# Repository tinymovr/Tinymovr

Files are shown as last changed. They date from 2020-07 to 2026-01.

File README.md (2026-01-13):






[Tinymovr is an affordable motor controller](https://tinymovr.com) with integrated encoder and CAN bus for precise control of 3-phase brushless motors (PMSMs). 

This repository holds the open source firmware, client library, hardware designs and documentation source.

> **Note**
>
> This is the latest stable version of the Tinymovr Firmware and Studio app. For the legacy 0.x.x version, check out the [legacy branch](https://github.com/tinymovr/Tinymovr/tree/attic/legacy).

## Getting Started

Please visit the [Quick Start Guide](https://tinymovr.readthedocs.io/en/latest/quickstart.html)

## Getting Help

[Full documentation is available at Readthedocs](https://tinymovr.readthedocs.io).

Please visit the [Discussions Page](https://github.com/tinymovr/Tinymovr/discussions) and the [Discord Server](https://discord.gg/vNvmpfthug) to ask any questions. If you are unable to find an answer to your question, you are welcome to [start a new discussion](https://github.com/tinymovr/Tinymovr/discussions/new/choose) or ask away at [our Discord server](https://discord.gg/vNvmpfthug).

If you would like to propose a feature or think you have found a bug, [open a new issue](https://github.com/tinymovr/Tinymovr/issues/new).

### Repository Structure

> **Note**: The `main` branch reflects the latest release. Development happens on [develop](https://github.com/tinymovr/Tinymovr/tree/develop).

The repository is organized as follows:

[firmware](./firmware/): Firmware for the PAC5527 MCU in Tinymovr

[studio](./studio/): Tinymovr Studio client software and library

[hardware](./hardware): Designs and drawings for related hardware

[docs](./docs): User documentation source (built with Sphinx)

See also: Developer documentation in root (ARCHITECTURE.md, CONTRIBUTING.md, etc.)

### Developer Documentation

For contributors and AI agents working with the codebase:

- **[ARCHITECTURE.md](ARCHITECTURE.md)** - System design and module organization
- **[CONTRIBUTING.md](CONTRIBUTING.md)** - Setup, workflow, and PR process
- **[SAFETY.md](SAFETY.md)** - Safety-critical constraints (read before modifying firmware)
- **[CLAUDE.md](CLAUDE.md)** - Navigation guide for AI agents

Additional technical documentation:
- [AVLOS_GUIDE.md](AVLOS_GUIDE.md) - Protocol modification workflow
- [CONVENTIONS.md](CONVENTIONS.md) - Code style and patterns
- [TESTING.md](TESTING.md) - Testing practices
- [STRUCTURE.md](STRUCTURE.md) - Directory organization
- [PAC5527_NOTES.md](PAC5527_NOTES.md) - MCU architecture

## Versioning

We use [SemVer](http://semver.org/) for versioning. For the versions available, see the [tags on this repository](https://github.com/tinymovr/tinymovr/tags). 

## Contributing

Pull requests are welcome. For major changes, please open an issue first to discuss what you would like to change.

**New contributors**: See [CONTRIBUTING.md](CONTRIBUTING.md) for setup instructions and workflow.

**AI agents**: See [CLAUDE.md](CLAUDE.md) for navigation and guidelines.

## License

[GPLv3](https://choosealicense.com/licenses/gpl-3.0/)

### External Links

[Tinymovr Website and Store](https://tinymovr.com)

[Blog](https://tinymovr.com/blogs/news)

[Discord server](https://discord.gg/vNvmpfthug)

[Project page on Hackaday](https://hackaday.io/project/168650-tinymovr-motor-controller)

[BLDC-Design-Help Repository](https://github.com/ThotAlion/BLDC-design-help), with lots of useful information and Tinymovr benchmarks

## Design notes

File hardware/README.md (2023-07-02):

### Tinymovr Hardware

This folder contains 3D models and drawings of the Tinymovr motor controller and associated hardware.

- [STEP files for Tinymovr R5.x and related accessories](./R5/)
- [STEP files for Tinymovr M5.x and related accessories](./M5/)
- [Tinymovr R3 STEP files](./R3/)
- [STL and STEP files for the Tinymovr Servo Kit, R2 and R5](./ServoKit/)
- [STEP files for the ACT8.3 Actuator](./Actuator/)
- [Miscellaneous STL/step files](./misc/), like a [jig for centering encoder magnets](./misc/magnet_jig.stl)

[CANine schematic files and models are now in a separate repository](https://github.com/tinymovr/CANine/tree/main/Hardware)

Unless otherwise specified, all designs are released under the MIT License.

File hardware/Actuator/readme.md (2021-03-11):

# ACT8.3 Actuator

ACT8.3 is a belt driven actuator with a 8.3:1 reduction, for the Tinymovr motor controller. In this video, I am testing the actuator up to 1.7Nm torque@15A.

This actuator uses the Tinymovr motor controller:

https://tinymovr.com

The actuator can be easily 3D printed on an FDM printer, with no supports.

The following Bill of Materials is recommended:

- 1x Tinymovr Motor Controller
- 1x Tarot 4108 Motor
- 1x 6705ZZ 25x32x4mm bearing
- 1x 6702ZZ 15x21x4mm bearing
- 2x 693ZZ 3x8x4mm bearings
- 2x GT2 158mm length 6mm width belts
- 1x GT2 Timing Pulley 12 teeth 4mm bore 6mm belt width
- 10x M2 threaded inserts
- 6x M2 bolts, 20mm length

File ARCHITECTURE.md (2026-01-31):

# Tinymovr System Architecture

**Document Type**: Architectural overview
**Target Audience**: AI agents, developers new to the codebase
**Focus**: System structure and design patterns, not implementation details

## Quick Reference

### Entry Points
- **Firmware Entry**: [firmware/src/main.c](firmware/src/main.c)
- **Control Loop**: [firmware/src/controller/controller.c](firmware/src/controller/controller.c)
- **API Specification**: [studio/Python/tinymovr/specs/](studio/Python/tinymovr/specs/)
- **Python Client**: [studio/Python/tinymovr/](studio/Python/tinymovr/)

### Related Documentation
- [SAFETY.md](SAFETY.md) - Safety-critical constraints for motor control
- [PAC5527_NOTES.md](PAC5527_NOTES.md) - MCU hardware architecture
- [AVLOS_GUIDE.md](AVLOS_GUIDE.md) - Communication protocol system
- [CLAUDE.md](CLAUDE.md) - Practical development guide

## System Components

Tinymovr consists of **two separate projects**:

### 1. Firmware (Embedded C)
- **Location**: [firmware/](firmware/)
- **Target**: Qorvo PAC5527 MCU (ARM Cortex-M4F)
- **Purpose**: Real-time motor control (Field-Oriented Control)
- **Architecture**: Bare-metal (no RTOS)
- **Build**: GNU Make + arm-none-eabi-gcc

### 2. Studio (Python)
- **Location**: [studio/Python/](studio/Python/)
- **Target**: Host computer (Linux, macOS, Windows)
- **Purpose**: User interface and motor configuration
- **Architecture**: Schema-driven client (Avlos framework)
- **Build**: Python package (pip install)

### Communication
- **Physical**: CAN bus (CAN 2.0B extended ID), UART
- **Protocol**: Avlos (schema-driven, auto-generated from YAML)
- **Direction**: Bidirectional (host ↔ firmware)

## Firmware Architecture

### Design Principles

1. **Real-Time**: Fixed 20 kHz control loop with <50 μs deadline
2. **Safety-First**: Automatic error detection and safe state transitions
3. **Modular**: 17 independent modules with clear responsibilities
4. **Cooperative Scheduling**: Single thread, interrupt-driven synchronization
5. **Resource-Constrained**: 32 KB RAM, 128 KB Flash

### Module Organization

**Location**: [firmware/src/](firmware/src/)

| Module | Purpose | Key Responsibilities |
|---|---|---|
| **main** | Entry point | Initialization sequence, startup |
| **system** | Platform | Clock config, reset, voltage monitoring |
| **controller** | Control | FOC loops (position → velocity → current) |
| **motor** | Motor mgmt | Calibration (R, L, pole pairs) |
| **sensor** | Encoder I/O | Multiple encoder types (MA7xx, AS5047, AMT22, Hall) |
| **observer** | State est. | Position/velocity estimation from encoder |
| **adc** | Sensing | Current measurement, ADC trigger |
| **gatedriver** | Actuation | PWM generation, Space Vector Modulation |
| **can** | Comm | CAN bus interface, Avlos endpoint dispatch |
| **uart** | Comm | UART interface (alternative to CAN) |
| **ssp** | I/O | SPI for external encoders |
| **nvm** | Storage | Configuration persistence to flash |
| **scheduler** | Timing | Interrupt sync, CPU load monitoring |
| **watchdog** | Safety | Communication timeout detection |
| **timer** | Hardware | PWM timer configuration |
| **utils** | Math | Fast trig, SVM algorithm |
| **rtt** | Debug | SEGGER RTT output (optional) |

**Dependencies**: See [ARCHITECTURE.md Module Map](#module-dependencies) for detailed dependency graph.

### Control Flow

#### Initialization
```
main() entry
  ↓
System initialization (clocks, peripherals)
  ↓
Load configuration from flash (or defaults)
  ↓
Initialize modules (ADC, CAN, timers, watchdog)
  ↓
Enable interrupts
  ↓
Enter control loop (never returns)
```

#### Control Loop Structure
```
Infinite loop:
  ├─ Error checking (overcurrent, undervoltage, etc.)
  ├─ State machine dispatch:
  │   ├─ IDLE: Motors disabled, safe state
  │   ├─ CALIBRATE: Multi-stage calibration sequence
  │   └─ CL_CONTROL: Closed-loop control active
  └─ Wait for ADC interrupt (20 kHz synchronization point)
```

#### Closed-Loop Control (when in CL_CONTROL state)
```
Every 50 μs (20 kHz):
  ├─ Read sensors (encoder, current)
  ├─ Update observers (position, velocity estimation)
  ├─ Position loop (if enabled): pos_error → vel_setpoint
  ├─ Velocity loop (if enabled): vel_error → current_setpoint
  ├─ Current loop (always): current_error → voltage_setpoint
  ├─ Space Vector Modulation: voltage → PWM duties
  └─ Update PWM outputs
```

### State Machine

**States**:
- **IDLE**: Safe state, motors off
- **CALIBRATE**: Executing calibration sequence
- **CL_CONTROL**: Closed-loop control active

**Transitions**:
- User command → State change
- Any error → Automatic transition to IDLE
- Watchdog timeout → Automatic transition to IDLE
- Calibration complete → Automatic transition to IDLE

**Safety**: Errors always force IDLE state. This cannot be disabled.

### Interrupt Architecture

**Priority** (highest to lowest):
1. **ADC IRQ** - Control loop synchronization (20 kHz)
2. **CAN RX** - Incoming messages
3. **UART RX** - Incoming messages (if using UART)
4. **SysTick** - System timing (1 kHz)
5. **Watchdog** - Safety timeout

**Design**: Short ISRs (<10 μs), set flags for main loop processing.

### Calibration System

**Multi-Stage Sequence** (all executed at 20 kHz):
1. **ADC Offset**: Zero current sensors (~1 second)
2. **Resistance (R)**: DC voltage/current measurement (~2 seconds)
3. **Inductance (L)**: AC impedance measurement (~1 second)
4. **Pole Pairs**: Rotation counting (variable duration)
5. **Encoder**: Eccentricity compensation (variable duration)

**Safety Features**:
- Voltage limits per board revision
- Range checking on measured values
- Warm-up and debouncing (recent addition)
- Automatic failure handling

### Memory Organization

**Flash** (128 KB):
- Bootloader: 4 KB @ 0x00000000
- Application: 124 KB @ 0x00001000

**RAM** (32 KB):
- Application: 31.75 KB
- Bootloader shared: 256 bytes

**Optimization**: Critical functions marked for RAM execution (zero wait states).

### Board Revision Support

Multiple hardware revisions supported via compile-time configuration:
- **R3.x**: Original design
- **R5.x**: Updated layout, improved EMI
- **M5.x**: Gimbal motor variant (lower current)

**Differences**: CAN pin assignments, current limits, calibration parameters.

## Studio Architecture (Python)

### Design Principles

1. **Schema-Driven**: API auto-generated from YAML specifications
2. **Device-Agnostic**: Supports multiple firmware versions simultaneously
3. **Unit-Aware**: Physical units (Pint library integration)
4. **Hardware-in-the-Loop**: Comprehensive test infrastructure
5. **Multi-Device**: Multiple Tinymovr devices on same bus

### Key Components

**Location**: [studio/Python/tinymovr/](studio/Python/tinymovr/)

| Component | Purpose |
|---|---|
| **specs/** | YAML API specifications (one per firmware version) |
| **config/** | Spec loading, device discovery, hash matching |
| **bus_router** | Message distribution to multiple devices |
| **bus_manager** | CAN bus connection with auto-reconnect |
| **channel** | Per-device communication channel |
| **device_discovery** | Automatic device detection via heartbeat |
| **codec** | Binary serialization/deserialization |
| **cli** | IPython-based command-line interface |
| **gui/** | Qt-based graphical interface |
| **tests/** | Hardware-in-the-loop test suite |

### Communication Stack

```
Application
  ↓
Device Object (dynamically generated from YAML spec)
  ↓
CANChannel (per device, identified by node_id)
  ↓
BusRouter (singleton, message distribution)
  ↓
BusManager (wraps python-can, auto-reconnect)
  ↓
python-can library
  ↓
CAN hardware adapter (CANine, slcan, socketcan, etc.)
```

### Schema-Driven API (Avlos)

**Workflow**:
```
YAML Spec
  ↓
avlos.generate (code generation tool)
  ├─→ Firmware C code (can_endpoints.c/h)
  ├─→ Firmware enums (tm_enums.h)
  └─→ Documentation (RST files)

YAML Spec (at runtime)
  ↓
avlos.deserialize
  ↓
Python Object Tree (dynamic attribute access)
```

**Benefits**:
- Single source of truth
- Firmware and client always synchronized
- Protocol versioning via hash
- Self-documenting API

### Device Discovery

**Process**:
1. Listen for CAN heartbeat messages
2. Extract protocol hash from heartbeat
3. Match hash to YAML spec
4. Deserialize spec into Python object
5. Create device instance

**Result**: Automatic instantiation of correct client version for each device.

### Testing Infrastructure

**Test Types**:
- **Simulation**: No hardware required, logic validation
- **HITL**: Hardware-in-the-loop, requires physical Tinymovr
- **Sensor-Specific**: Tests for particular encoder types
- **End-of-Line**: Comprehensive production tests

**Test Markers** (pytest):
- `@pytest.mark.hitl_default`
- `@pytest.mark.sensor_amt22`
- `@pytest.mark.sensor_as5047`
- `@pytest.mark.sensor_hall`
- `@pytest.mark.eol`
- `@pytest.mark.dfu`

## Communication Protocol (Avlos)

### Design

- **Schema-Driven**: Defined in YAML, not hand-coded
- **Hierarchical**: Tree structure of attributes
- **Typed**: Strong type system (float, uint32, bool, enums, etc.)
- **Versioned**: Protocol hash ensures compatibility
- **Bidirectional**: Read/write/call operations

### CAN Bus Encoding

**Arbitration ID** (29-bit extended):
- Node ID field (device address)
- Protocol hash field (version identifier)
- Endpoint ID field (parameter/function identifier)

**Payload**:
- Binary serialization (little-endian)
- Up to 8 bytes per frame
- Type-specific encoding (float, int, string, etc.)

### Version Management

**Multi-Version Support**:
- Multiple YAML specs for different firmware versions
- Runtime hash matching
- Graceful degradation if hash mismatch
- Hash aliases for backward compatibility

## Hardware Architecture

### Supported Boards

| Revision | Family | Application | Current Range |
|---|---|---|---|
| R3.x | R3 | High-current | 5-30 A |
| R5.x | R5 | High-current (improved) | 5-30 A |
| M5.x | M5 | Gimbal motors | 1-10 A |

**Compile-Time Selection**: `make release REV=R52`

### Encoder Support

**Types**:
1. MA7xx (MPS magnetic) - Onboard
2. AS5047 (AMS magnetic) - External SPI
3. AMT22 (CUI absolute) - External SPI
4. Hall effect - 3× digital inputs

**Normalization**: All encoders normalized to 13-bit resolution (8192 ticks/rev).

**Dual Sensor**: Supports simultaneous commutation and position sensors.

## Key Design Decisions

### Firmware

1. **No RTOS**: Bare-metal for predictability and low overhead
2. **Fixed 20 kHz PWM**: Simplifies timing analysis, above audible range
3. **RAM Execution**: Critical functions run from RAM for deterministic timing
4. **Cooperative Scheduling**: Single control thread, no preemption
5. **Automatic Safety**: Errors force IDLE state, cannot be disabled

### Studio

1. **Schema-Driven**: Avlos framework eliminates manual wrapper coding
2. **Dynamic Objects**: Python objects created at runtime from YAML
3. **Unit System**: Pint integration for physical units
4. **Multi-Device**: BusRouter enables multiple devices on one bus
5. **Version Agnostic**: Supports multiple firmware versions simultaneously

### Protocol

1. **CAN Bus**: Industry-standard, reliable, multi-drop
2. **Extended ID**: 29-bit allows encoding of version and endpoint
3. **Binary Encoding**: Efficient, minimal bandwidth
4. **Hash Versioning**: Detects incompatibilities automatically

## Module Dependencies

### Firmware Core Dependencies

```
main
 ├─→ system (clocks, reset)
 ├─→ nvm (config loading)
 ├─→ adc (current sensing)
 ├─→ can (communication)
 ├─→ uart (alternative comm)
 ├─→ timer (PWM setup)
 ├─→ watchdog (safety)
 └─→ controller (control loop)
      ├─→ motor (calibration, parameters)
      ├─→ observer (state estimation)
      │    └─→ sensor (encoder reading)
      │         └─→ ssp (SPI for external encoders)
      ├─→ gatedriver (PWM output)
      │    └─→ timer (hardware config)
      └─→ scheduler (timing sync)
```

### Studio Core Dependencies

```
Application
 └─→ Device (from config.create_device)
      ├─→ CANChannel (from channel.py)
      │    ├─→ BusRouter (singleton from bus_router.py)
      │    │    └─→ BusManager (from bus_manager.py)
      │    │         └─→ python-can
      │    └─→ MultibyteCodec (from codec.py)
      └─→ Avlos-generated attributes (from specs/*.yaml)
           └─→ Pint units (if unit specified in YAML)
```

## Critical File Reference

### Firmware
- [firmware/src/main.c](firmware/src/main.c) - Entry point
- [firmware/src/controller/controller.c](firmware/src/controller/controller.c) - Control loop
- [firmware/src/motor/motor.c](firmware/src/motor/motor.c) - Calibration
- [firmware/src/config.h](firmware/src/config.h) - System constants
- [firmware/src/common.h](firmware/src/common.h) - Board revisions, includes
- [firmware/Makefile](firmware/Makefile) - Build system

### Studio
- [studio/Python/tinymovr/specs/](studio/Python/tinymovr/specs/) - API definitions (YAML)
- [studio/Python/tinymovr/config/config.py](studio/Python/tinymovr/config/config.py) - Spec loading
- [studio/Python/tinymovr/bus_router.py](studio/Python/tinymovr/bus_router.py) - Message routing
- [studio/Python/tinymovr/channel.py](studio/Python/tinymovr/channel.py) - Device communication
- [studio/Python/tests/tm_test_case.py](studio/Python/tests/tm_test_case.py) - Test base class

### Protocol
- [avlos_config.yaml](avlos_config.yaml) - Code generation config
- [firmware/src/can/can_endpoints.h](firmware/src/can/can_endpoints.h) - Generated endpoints (C)
- [firmware/src/tm_enums.h](firmware/src/tm_enums.h) - Generated enums (C)

## Build System

### Firmware Build

**Toolchain**: GNU ARM Embedded (arm-none-eabi-gcc)
**Build Tool**: GNU Make
**Targets**: `debug`, `release`, `clean`
**Board Selection**: `REV=R53` (or R52, M51, etc.)

**Linker Script**: [firmware/pac55xx.ld](firmware/pac55xx.ld) - Memory layout

### Studio Build

**Python Version**: 3.9+
**Package Manager**: pip
**Install**: `pip install -e .` (editable mode)
**Optional GUI**: `pip install -e .[gui]`

### Code Generation

**Tool**: Avlos (Python package)
**Command**: `avlos from file <spec_file>.yaml`
**Input**: YAML specs in [studio/Python/tinymovr/specs/](studio/Python/tinymovr/specs/)
**Output**: C code, enums, documentation

## Development Environment

### Required Tools

**Firmware**:
- arm-none-eabi-gcc
- GNU Make
- PAC55xx SDK (download from Qorvo)
- Optional: J-Link debugger

**Studio**:
- Python 3.9+
- CAN interface hardware
- pytest (for testing)

**Documentation**:
- Sphinx
- Furo theme

### Debug Interfaces

**Firmware**:
- SWD/JTAG (pins: SWDIO, SWCLK)
- SEGGER RTT (zero-overhead debug output)

**Studio**:
- python-can debug logging
- pytest verbose output

## Cross-References

For detailed information, see:
- **Safety Constraints**: [SAFETY.md](SAFETY.md)
- **MCU Hardware**: [PAC5527_NOTES.md](PAC5527_NOTES.md)
- **Protocol System**: [AVLOS_GUIDE.md](AVLOS_GUIDE.md)
- **Development Guide**: [CLAUDE.md](CLAUDE.md)
- **Contributing**: [CONTRIBUTING.md](CONTRIBUTING.md)
- **User Documentation**: [docs/](docs/)

---

**Document Focus**: Architectural patterns and structure, not implementation details.
**For Implementation**: See source code and related documentation above.

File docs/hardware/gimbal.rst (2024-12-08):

.. _gimbal-motors:

*************
Gimbal Motors
*************

.. |cli| raw:: html

   <span style="padding:3px 10px;margin: 10px auto; background:#85dff1; border-radius: 12px; font-family: sans-serif; font-size: 14px;">CLI</span>

.. |gui| raw:: html

   <span style="padding:3px 10px;margin: 10px auto; background:#85f1df; border-radius: 12px; font-family: sans-serif; font-size: 14px;">GUI</span>

.. _gimbal-introduction:

Introduction
------------

Tinymovr can drive gimbal-style brushless motors in open loop current control, by disabling current sensing. 

.. warning::
   * This mode is not recommended for Tinymovr M5, which is a specialized gimbal driver and can do closed loop current control with gimbal motors.

What is a gimbal motor anyway?

A gimbal motor is a 3-phase brushless motor whose stator is wound with many turns, and as such exhibits much larger resistance and inductance compared to the high-current brushless motors used to provide lift to drones, rc planes etc. Gimbal motors are used in... well... camera gimbals mainly. Similar motors can be found in light robotic joints. Such motors offer smooth motion and require small currents to produce torque compared to the 'high current' brushless motors. This in turn can help minimize the size of the motor driver and associated wires etc. Note that we refer to reduction of current through the stator windings and not the power converted to heat as a result of Joule heating of stator windings, which is still the same for the same amount of torque.

To achieve closed-loop current control, motor controllers such as Tinymovr use current measurement resistors in each phase (usually in series with the low-side mosfet) to estimate the current in the motor windings. These resistors have low resistance (in the range of a few milliOhms at most), to limit power dissipation in the resistor and allow operation in wide current ranges (up to several tens of Amps, even hundreds). The drawback is that current measurements exhibit noise of 100s of mA, and as such do not offer accurate measurements of small currents.

The gimbal mode of Tinymovr disables closed-loop current control. The commanded currents are converted to voltages using basic resistance and inductance formulas. 

.. _enabling-gimbal-mode:

Enabling Gimbal Mode
--------------------

.. warning::
   * DO NOT perform calibration on a gimbal motor without setting gimbal mode first! There is a risk of damaging the motor and board.
   
   * Using arbitrary resistance and inductance settings can damage your motor and board.

To enable gimbal mode, set the motor configuration as follows:

|gui|

|cli|

.. code-block:: python

    >>>tm1.motor.type = 1 # gimbal type
    >>>tm1.motor.R = {motor_resistance}
    >>>tm1.motor.L = {motor_inductance}
    >>>tm1.motor.I_cal = {calibration_current}

Example

.. code-block:: python

    >>>tm1.motor.type = 1
    >>>tm1.motor.R = 5
    >>>tm1.motor.L = 2e-3
    >>>tm1.motor.I_cal = 0.5

     >>>tm1.set_motor_RL(5, 0.002)

This specifies a motor with 5 Ohms resistance, 2 Millihenries inductance and 0.5Amps calibration current.
Alternatuvely, using the units interface:

.. code-block:: python

    >>>tm1.motor.type = 1 # gimbal type
    >>>tm1.motor.R = 5 * Ohm
    >>>tm1.motor.L = 2e-3 * Henry
    >>>tm1.motor.I_cal = 0.5 * Amps

Control that the settings are correct:

|cli|

.. code-block:: python
    
    >>>tm1.motor

Ensure the values above are correct. You can now calibrate the motor:

|gui| Set Gimbal Motor Parameters

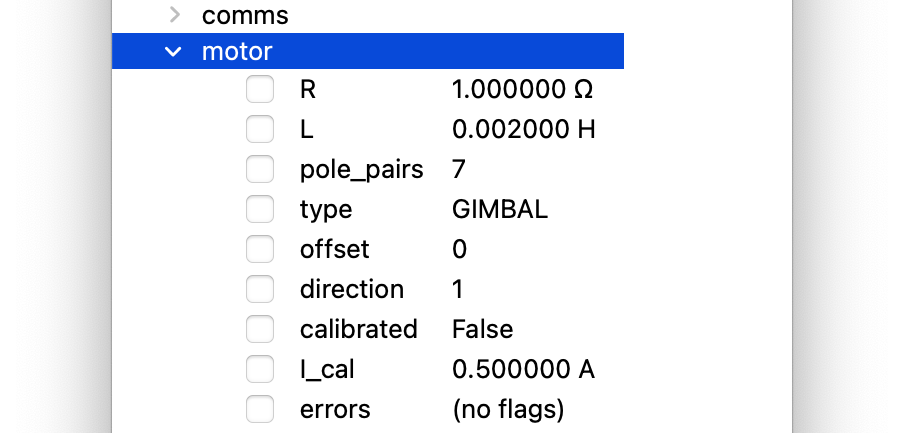
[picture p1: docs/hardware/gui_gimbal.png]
Set Gimbal Motor Parameters


|cli|

.. code-block:: python
    
    >>>tm1.controller.calibrate()

Because the motor is set as gimbal, calibration will bypass resistance and inductance measurement, and will only calculate pole pairs, offset and direction. After calibration `tm1.motor.calibrated` should have a value of True:

|gui| Calibrate Motor

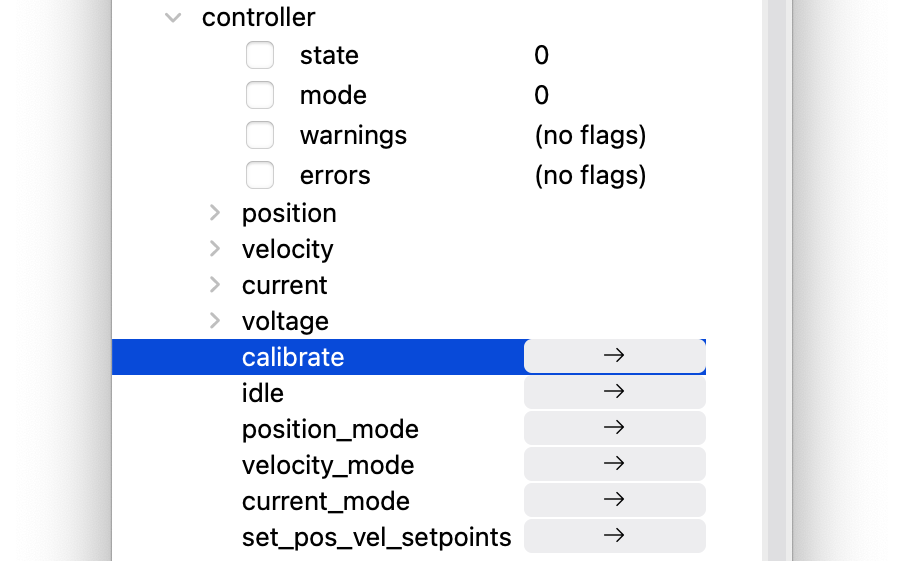
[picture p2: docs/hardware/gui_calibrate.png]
Calibrate Motor


|cli|

.. code-block:: python
    
    >>>tm1.motor.calibrated
    True

Controlling the Motor
---------------------

Gimbal mode has identical functionality as the default high-current mode. Position, velocity and current control modes are supported. Depending on your motor charaacteristics, you may have to tune the control gains to achieve optimal performance. In addition, due to the fact that current control is open loop, high angular velocities may not be available.

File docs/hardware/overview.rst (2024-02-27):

.. _hardware-overview:

*****************
Hardware Overview
*****************

R5.x
****

Tinymovr R5.x is the latest Tinymovr revision. It features increased connectivity in a reduced footprint.

Board Dimensions (R5.0, R5.1)
#############################

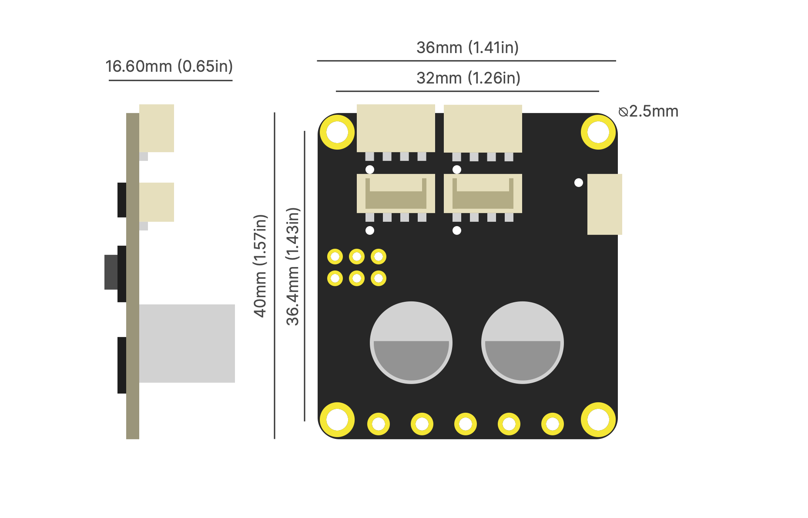
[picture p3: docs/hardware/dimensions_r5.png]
Tinymovr R5 dimensions


Connectivity (R5.0, R5.1)
#########################

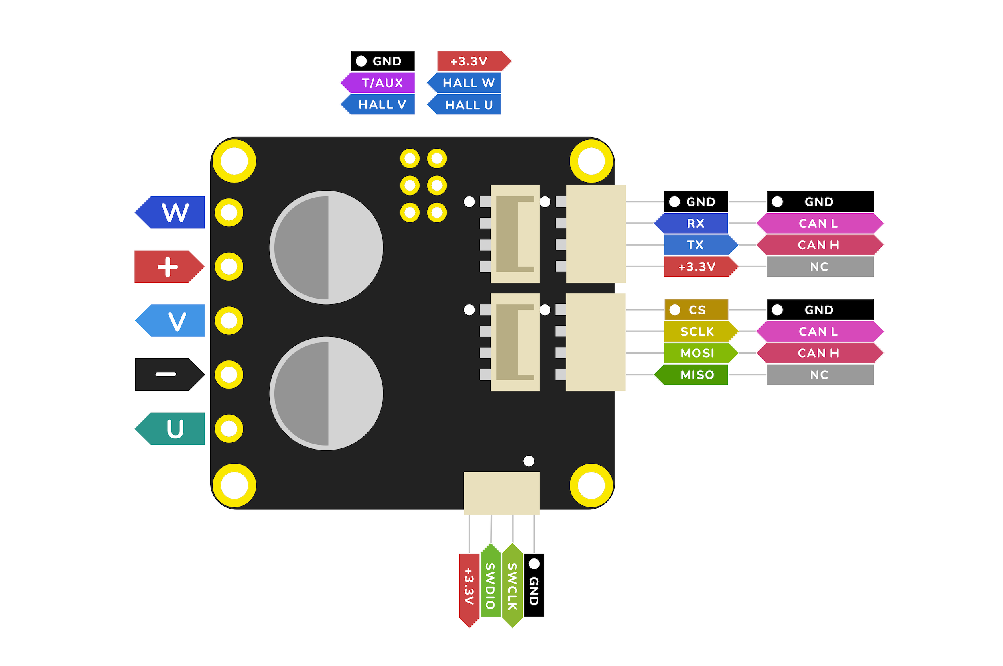
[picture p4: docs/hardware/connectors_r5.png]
Tinymovr R5 connectors and pinouts


.. warning::
   The UART pins in Tinymovr R5.1 have the silkscreen reversed. If you are planning to use UART with R5.1, consult :ref:`r51-erratum-1`. This only affects R5.1 boards.

Board Dimensions (R5.2)
#######################

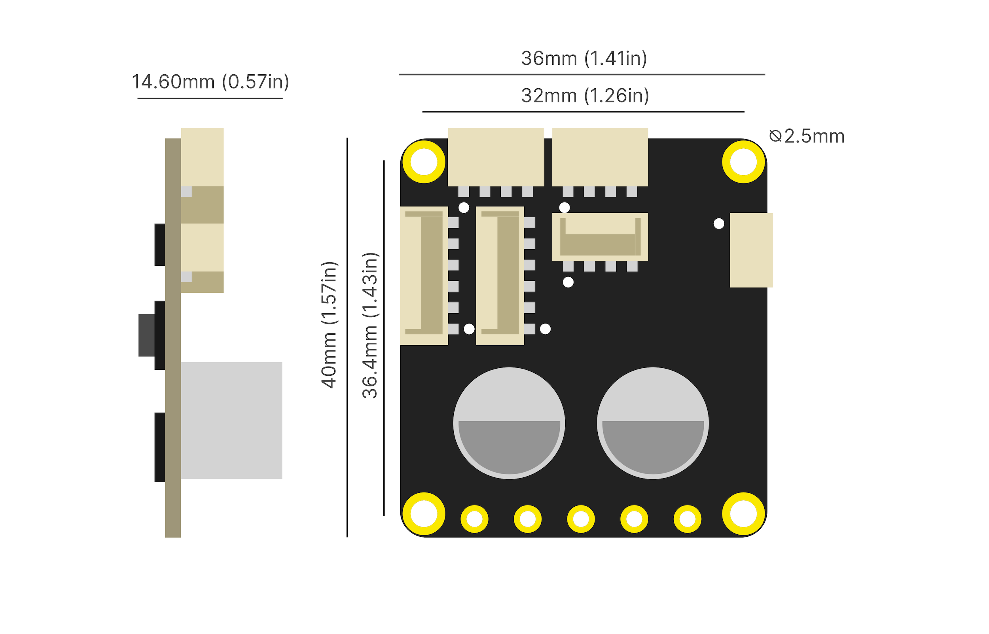
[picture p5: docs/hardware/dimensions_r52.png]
Tinymovr R5.2 dimensions


Connectivity (R5.2)
###################

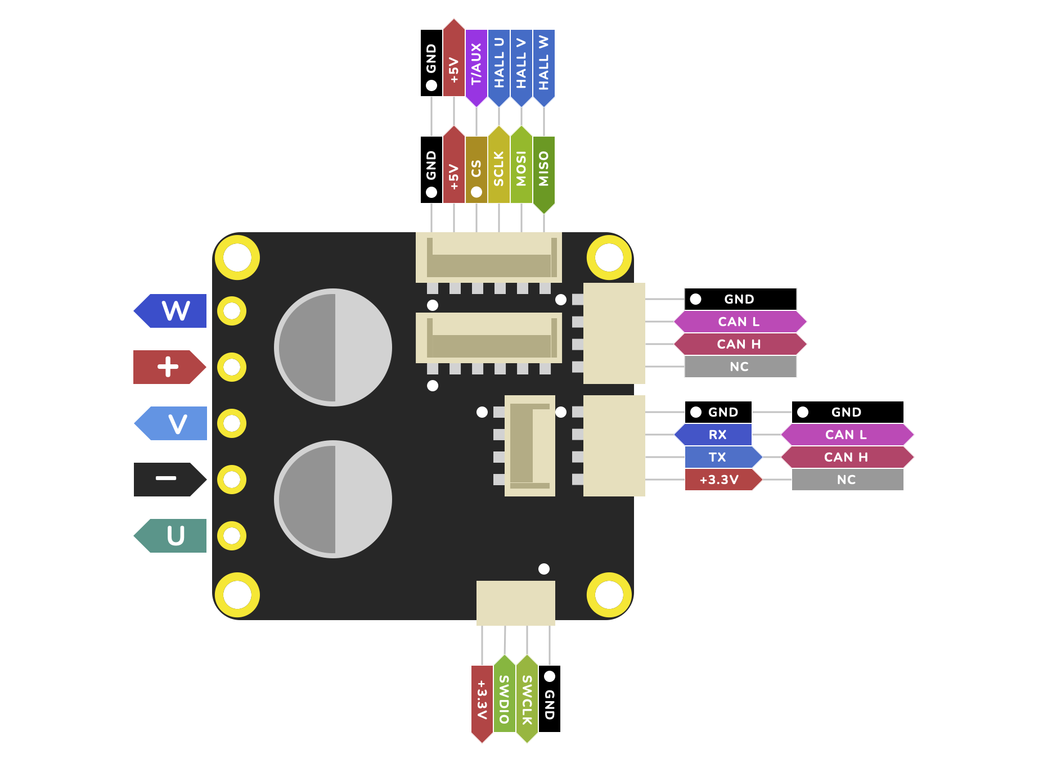
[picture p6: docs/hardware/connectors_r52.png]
Tinymovr R5.2 connectors and pinouts


M5.x
****

Tinymovr M5.x is is our specialized driver for gimbal motors and light robotic joints. It features a very compact footprint and 5A max drive.

Board Dimensions (M5.1, M5.2)
#############################

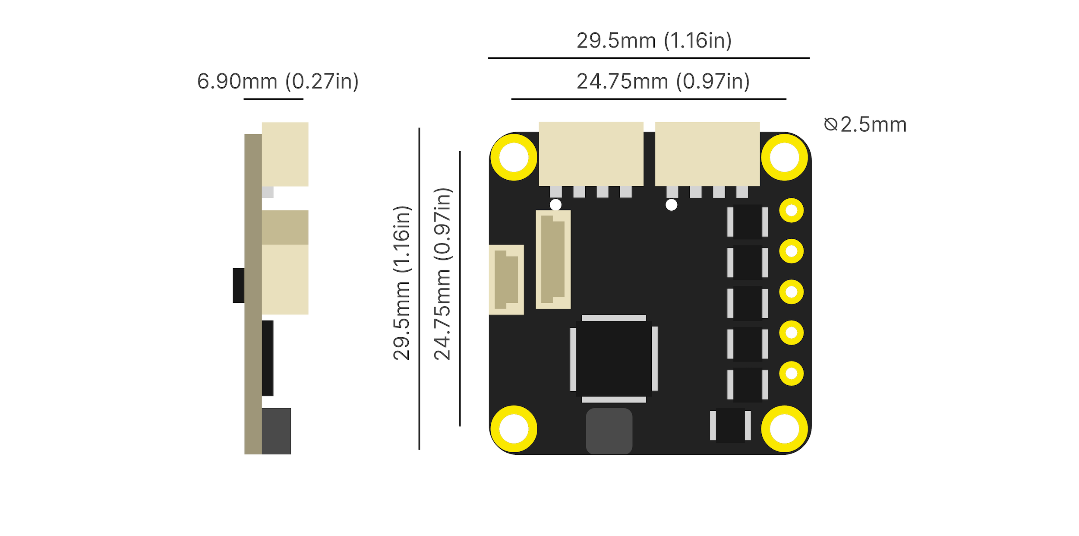
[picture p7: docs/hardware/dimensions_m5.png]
Tinymovr M5 dimensions


Connectivity (M5.1)
#########################

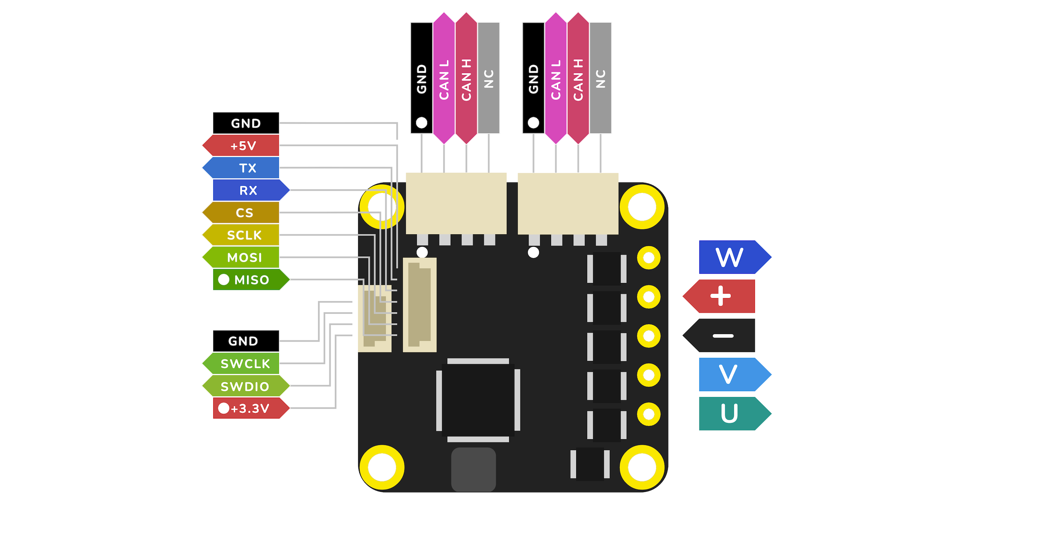
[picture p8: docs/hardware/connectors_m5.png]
Tinymovr M5.1 connectors and pinouts


Connectivity (M5.2)
#########################

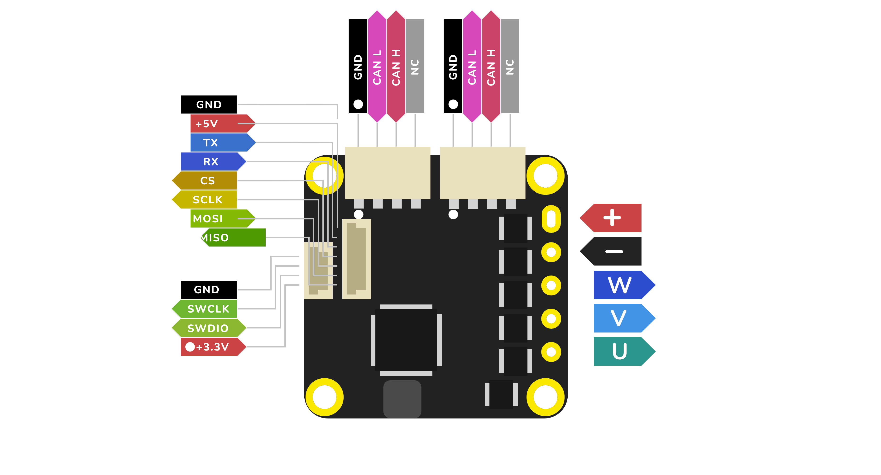
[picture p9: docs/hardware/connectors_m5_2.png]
Tinymovr M5.2 connectors and pinouts


R3.x
****************

R3.x is the previous Tinymovr revision, with CAN and UART connectivity.

Board Dimensions (R3.x)
#######################

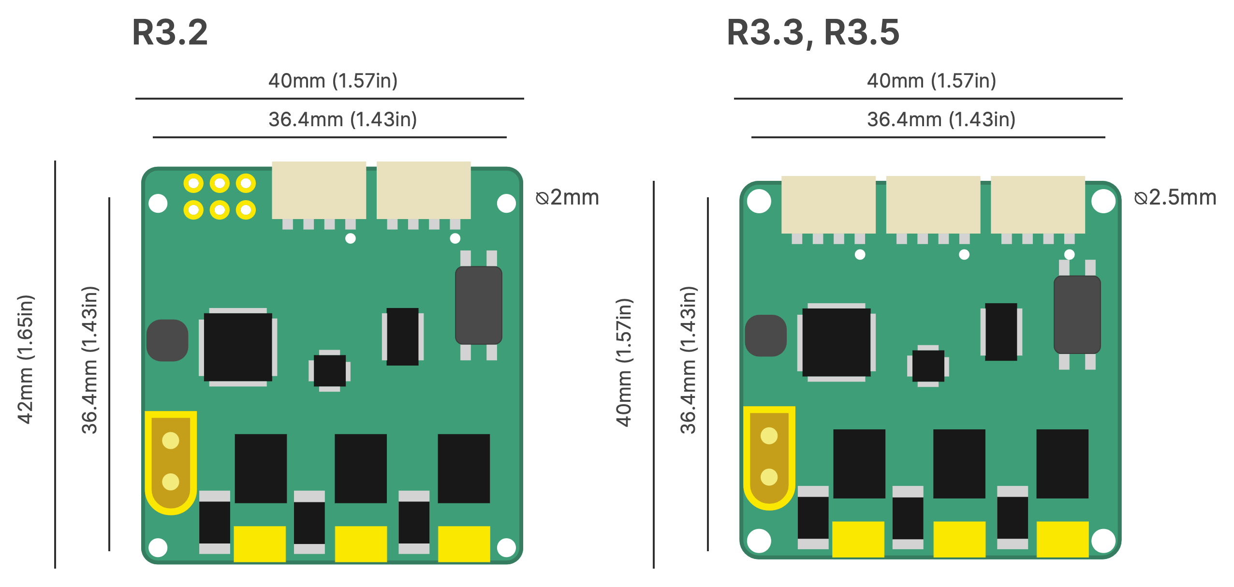
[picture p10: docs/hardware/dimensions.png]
Tinymovr R3.x dimensions


Connectivity (R3.x)
###################

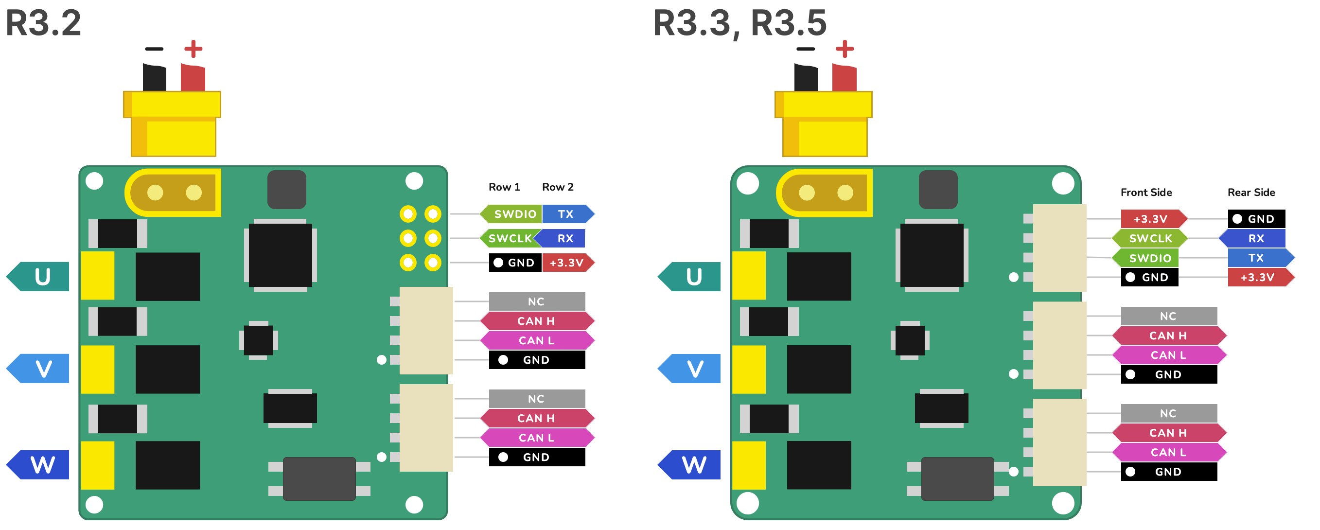
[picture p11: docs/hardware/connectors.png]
Tinymovr R3.x connectors and pinouts


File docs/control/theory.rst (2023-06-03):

.. _Control theory:

******************
Control Principles
******************

This document provides a high-level introduction to the essential control principles in Tinymovr. Additional documentation regarding specific high-level control concepts is available in the :ref:`features` section.

Permanent Magnet Synchronous Motors (PMSMs)
###########################################

PMSMs is a category which includes the majority of hobby-grade brushless motors. PMSMs produce torque through the interaction of the magnetic field of the rotor permanent magnets with the magnetic field generated by the stator coils. The stator magnetic field "rotates" at a rate that is an integer multiple of the rotor rate of rotation, this is why this type of motor is termed "synchronous". 

This is also why, the motor controlled needs to be able to estimate the angular position of the rotor, in order to derive the stator magnetic field that produces torque. Many controllers estimate the rotor using magnetic encoder readings, which is then converted to electrical angle in software. This is termed *sensored estimation*, and this is the method employed in Tinymovr. In contrast, ESCs such as those used in drones use voltage feedback from one of the motor phases to estimate rotor position. This is termed *sensorless estimation*.

Field Oriented Control (FOC)
############################

Field Oriented Control (FOC) is a control scheme employed in brushless motor applications, offering superior performance compared to other algorithms. Although FOC requires more computational power due to its complexity, advancements in technology have made it increasingly accessible. Modern 32-bit microcontrollers can now execute FOC algorithms at high rates, contributing to its widespread adoption. By directly controlling the current in the motor phases, FOC enables precise torque management, resulting in enhanced performance and efficiency for various applications.

The FOC algorithm comprises three main elements:

1. Precise 3-phase current estimation
2. Transformation of 3-phase measurements to rotating frame.
3. Regulation of the rotational frame variables.

Measuring Phase Currents
************************

In order for FOC to work, the currents in the three phases (U, V, W) of the motor must be precisely estimated. This is done with the help of shunt resistors. Shunt resistors are high-power elements with low, precisely known resistance values, that are placed in series to the low-side mosfet sources, and enable current measurement by measuring the voltage differential across their terminals. Hardware and software filtering techniques improve current measurement accuracy.

As the motor phases are connected, current measurement in each of the three phases is redundant, and measurement in two phases would theoretically suffice. Nonetheless, having all three measurements allows for better accuracy through averaging of measurement errors. This is why Tinymovr uses three phase current measurement.

Reference Frames
****************

Next, the 3-phase measurements are transformed to the rotating frame of the rotor which is termed dq. The relevant transformation is known as the dq0 transform. The resulting quantities are the direct (d) current and quadrature (q) current. Motor torque is attributed to the quadrature component, while the direct component is minimized (except in the case of :ref:`flux-braking-feature`).

Current Regulation and Motor Parameter Identification
*****************************************************

Because the d and q quantities represent DC signals in the rotational frame, it is possible to apply PI regulation to control current. For optimal regulation, the PI current regulation requires correct identification of proportional and integral gains. Tinymovr uses the method proposed in [1] to calculate the gains from the resistance and inductance motor parameters. The parameters are measured automatically by the firmware during the calibration procedure. 

Thus the whole process is automated, and you don't need to worry about it.

Control loop Overview
#####################

On top of the FOC loop, Tinymovr implements an embedded control loop. This control loop runs at a 20kHz rate.

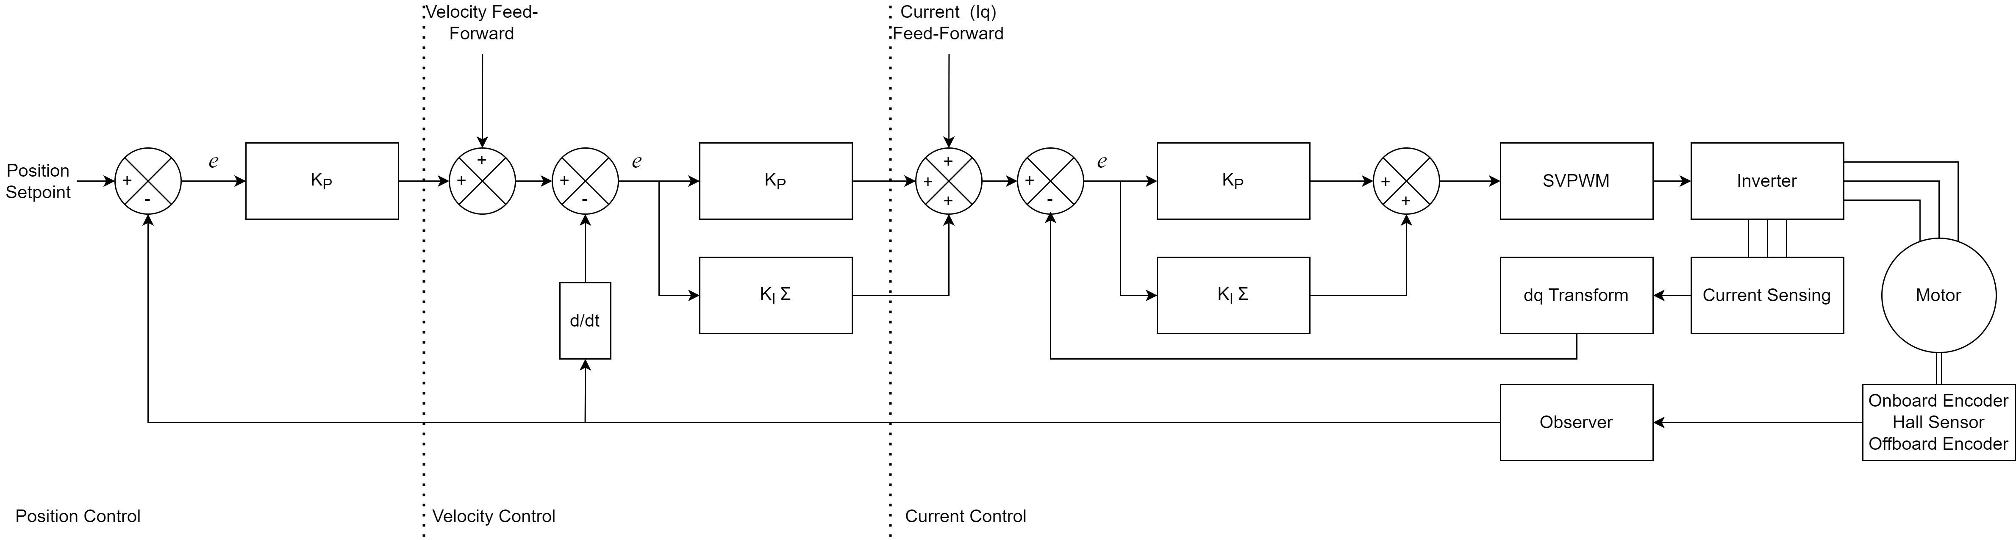
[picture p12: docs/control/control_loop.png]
Tinymovr Control Loop


Position mode
*************

This is the most versatile mode, it accepts a position setpoint, and additional velocity and current feedforward terms.

You can tune separately each gain of the loop.

**P_p**: The gain of the position proportional term

**P_v**: The gain of the velocity proportional term

**I_v**: The gain of the velocity integral term

The integral term is especially useful for tracking positions at low velocities. You can set it to zero for greater position control bandwith.

Velocity Integrator Deadband
----------------------------

The integrator deadband is a setting that is useful in minimizing the "hunting" phenomenon, where the rotor oscillates around the setpoint at standstill. This phenomenon is due to interaction of integrator windup and the non-linearities of cogging torque. The integrator deadband feature is only active in position control mode and disables the integrator term update within a configurable window around the position setpoint (the "deadband").

Take a look at the :ref:`integrator-deadband` endpoint for specifics.

Example applications
--------------------

Robot joint control, CNC axis.

Velocity mode
*************

In this mode the controller accepts a velocity setpoint, and an optional current feedforward term.

Example applications
--------------------

Drone and aircraft propeller
    Large airframes where constant angular velocity is desired, without exceptionally high RPM (i.e. 5000rpm or less).
Industrial Automation
    Where constant RPM is required, regardless of load. Pumps, ventilators, cutters, drills, etc.
Wheel propulsion
    For brushless wheel based projects like differential drives or rovers.

Current mode
*************

This is the most direct mode, where you can specify current setpoints, that are direct inputs to the FOC algorithm.

Example applications
--------------------

Force based control
    Robots controlled in admittance or impedance.
E-scooter
    Where the throttle input is mapped to the current target. It translates to the acceleration of the vehicle, which feels more natural than a velocity input.

Further Reading
###############

Additional documentation regarding specific high-level control concepts in Tinymovr is available in the :ref:`features` section.

`Vector Control (Wikipedia) <https://en.wikipedia.org/wiki/Vector_control_(motor)>`_

`Sensorless Field Oriented Control of Brushless PMSMs <https://krex.k-state.edu/dspace/bitstream/handle/2097/1507/JamesMevey2009.pdf;jsessionid=820C6C90C0851225CAE19AF829939F2A?sequence=1>`_

References
##########

[1] `High Performance Brushless DC Motor Control <https://www.ti.com/cn/lit/an/sprt702/sprt702.pdf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>`_

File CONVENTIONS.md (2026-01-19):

# Tinymovr Code Conventions

**Purpose**: Code style guidelines and common patterns for Tinymovr development.

**Target Audience**: Developers and AI agents contributing to firmware or Python client.

## C/C++ Style (Firmware)

### General Rules

- **Style**: K&R-inspired
- **Indentation**: 4 spaces (no tabs)
- **Naming**: Descriptive variable names (`position_setpoint`, not `ps`)
- **Comments**: Explain non-obvious logic, not obvious code
- **Precision**: Use `float` (not `double`) - Cortex-M4F has single-precision FPU only

### Function Naming

```c
// Module prefix + action + object
float motor_get_temperature(void)       // Getter
void controller_set_pos_setpoint(float) // Setter
bool ADC_calibrate_offset(void)         // Action
```

### Variable Naming

```c
// Good: Descriptive, clear purpose
float R_current = motor_measure_resistance();
float delta_R = R_current - motor_config.R_calibrated;
float delta_T = delta_R / (motor_config.R_calibrated * COPPER_TEMP_COEFF);
return CALIBRATION_TEMP + delta_T;

// Bad: Cryptic, unclear
float r=mr();
float d=r-c.r;
return 25+d/(c.r*0.00393);
```

### RAM Functions

Functions must be placed in RAM using `TM_RAMFUNC` or `PAC5XXX_RAMFUNC` for two distinct reasons:

#### 1. Flash Write Operations (Hardware Constraint)

**CRITICAL**: Code that writes or erases flash **cannot execute from flash** - it must run from RAM. This is a hardware limitation: the flash controller cannot simultaneously execute code and modify flash memory.

```c
PAC5XXX_RAMFUNC void flash_write(uint8_t *dest, uint8_t *src, uint32_t size) {
    // Must run from RAM because flash is being modified
    // Executing from flash during write would cause undefined behavior
}

PAC5XXX_RAMFUNC void flash_erase_page(uint32_t page_num) {
    // Must run from RAM - cannot execute from flash during erase
}
```

**Rule**: Any function that writes/erases flash **must** be `PAC5XXX_RAMFUNC`. See [flash_func.c](firmware/src/nvm/flash_func.c).

#### 2. Control Loop Performance (Zero Wait State)

Mark control loop functions with `TM_RAMFUNC` for deterministic zero-wait-state execution:

```c
TM_RAMFUNC void CLControlStep(void) {
    // Runs at 20 kHz from RAM for predictable timing
}
```

**Rule**: If called every 50 μs (20 kHz), it **must** be `TM_RAMFUNC` for performance.

#### Important: When NOT to Use RAMFUNC

**Do NOT add RAMFUNC unless required by one of the two reasons above.** Unnecessary RAMFUNC markers:
- Waste limited RAM space (only 64 KB total)
- Trigger GCC debug symbol bugs on some compiler versions
- Provide no benefit for non-critical code

Example: NVM wear leveling functions (`nvm_wl_scan_slots`, `calculate_checksum`) do NOT need RAMFUNC:
- Not called from control loop (performance reason doesn't apply)
- Don't write to flash themselves (hardware constraint doesn't apply)
- Called by `nvm_save_config` which calls `flash_write`, but that's fine - only `flash_write` needs RAM placement

### Performance Guidelines

**Float Precision**:
```c
float value = 3.14f;  // ✓ Hardware FPU
double value = 3.14;  // ❌ Software emulation (10-100× slower)
```

**Division Optimization**:
```c
// Bad: Integer division (no hardware divider)
int result = value / 123;

// Good: Pre-compute reciprocal
float result = value * (1.0f / 123.0f);
```

**Blocking Operations** (Never in control loop):
- ❌ `printf()`, `SEGGER_RTT_printf()`
- ❌ `delay()`, busy-wait loops
- ❌ `malloc()`, `free()`
- ❌ Large loops (>100 iterations)

**Allowed Operations**:
- ✓ Simple arithmetic (`+`, `-`, `*`)
- ✓ Fast approximations (`fast_sin()`, `fast_cos()`)
- ✓ Lookup tables
- ✓ Conditional branches

### Example: Well-Formatted Function

```c
float motor_get_temperature(void)
{
    // Estimate temperature from resistance change using copper temp coefficient
    // Formula: T = T_cal + ΔR / (R_cal × α)
    // where α = 0.00393/°C for copper

    MotorConfig *config = motor_get_config();
    float R_cal = config->phase_resistance;  // Resistance at calibration
    float T_cal = 25.0f;  // Assumed calibration temperature (°C)
    float alpha = 0.00393f;  // Copper temperature coefficient

    // Measure current resistance
    float R_current = motor_measure_resistance();

    // Calculate temperature change
    float delta_R = R_current - R_cal;
    float delta_T = delta_R / (R_cal * alpha);

    return T_cal + delta_T;
}
```

## Python Style (Studio)

### General Rules

- **Standard**: PEP 8
- **Formatter**: Black (line length: 127 characters)
- **Type Hints**: Encouraged for public APIs
- **Docstrings**: Required for public APIs (Google style)

### Function Example

```python
def calibrate_motor(current: float, timeout: float = 10.0) -> bool:
    """
    Calibrate motor with specified current.

    Args:
        current: Calibration current in amperes
        timeout: Maximum time to wait in seconds

    Returns:
        True if calibration succeeded, False otherwise

    Raises:
        ValueError: If current is negative or exceeds safe limits
    """
    if current < 0 or current > MAX_CALIBRATION_CURRENT:
        raise ValueError(f"Invalid calibration current: {current}")

    # Implementation...
    return True
```

### Test Naming

```python
class TestMyFeature(TMTestCase):
    @pytest.mark.hitl_default
    def test_feature_basic(self):
        """Test basic functionality of feature"""
        pass

    @pytest.mark.hitl_default
    def test_feature_edge_case(self):
        """Test edge case handling"""
        pass
```

### Unit Handling

```python
from pint import UnitRegistry
ureg = UnitRegistry()

# Reading returns unit-aware quantity
voltage = tm.Vbus  # Returns: 24.0 <Unit('volt')>

# Writing accepts units
tm.controller.current.Iq_setpoint = 2.5 * ureg.ampere

# Or plain floats (assumes base unit)
tm.controller.current.Iq_setpoint = 2.5  # Interpreted as amperes
```

## YAML Style (Avlos Specs)

### General Rules

- **Indentation**: 2 spaces (consistent with existing specs)
- **Structure**: Follow existing patterns in [tinymovr_2_3_x.yaml](studio/Python/tinymovr/specs/tinymovr_2_3_x.yaml)
- **Documentation**: Clear `summary` for all endpoints
- **Ordering**: Keep logical grouping (related attributes together)

### Endpoint Pattern

```yaml
- name: parameter_name
  dtype: float                    # Data type
  unit: ampere                    # Physical unit (if applicable)
  meta: {dynamic: True}           # Metadata (optional)
  getter_name: module_get_parameter  # C getter function
  setter_name: module_set_parameter  # C setter function (optional)
  summary: Brief description of what this parameter represents.
```

### Nested Attributes

```yaml
- name: controller
  remote_attributes:
    - name: position
      remote_attributes:
        - name: setpoint
          dtype: float
          unit: tick
          getter_name: controller_get_pos_setpoint
          setter_name: controller_set_pos_setpoint
          summary: Position setpoint in user frame.
```

### Enums

```yaml
- name: state
  options: [IDLE, CALIBRATE, CL_CONTROL]
  getter_name: controller_get_state
  setter_name: controller_set_state
  summary: Current controller state.
```

### Flags (Bitmasks)

```yaml
- name: errors
  flags: [UNDERVOLTAGE, OVERCURRENT]
  meta: {dynamic: True}
  getter_name: system_get_errors
  summary: System errors as bitmask.
```

## Common Code Patterns

### Pattern: Adding State Variable to Firmware Module

**Header** ([firmware/src/module/module.h](firmware/src/module/module.h)):
```c
typedef struct {
    float my_value;  // New state variable
    // ... existing fields ...
} ModuleState;
```

**Implementation** ([firmware/src/module/module.c](firmware/src/module/module.c)):
```c
static ModuleState state = {
    .my_value = 0.0f,  // Default initialization
};

float module_get_my_value(void) {
    return state.my_value;
}

void module_set_my_value(float value) {
    state.my_value = value;
}
```

### Pattern: Persistent Configuration (Saved to Flash)

**Header** ([firmware/src/module/module.h](firmware/src/module/module.h)):
```c
typedef struct {
    float my_parameter;  // Will be saved to NVM
} ModuleConfig;

ModuleConfig *module_get_config(void);
void module_restore_config(ModuleConfig *config_);
```

**Implementation** ([firmware/src/module/module.c](firmware/src/module/module.c)):
```c
static ModuleConfig config = {
    .my_parameter = 10.0f,  // Default value
};

ModuleConfig *module_get_config(void) {
    return &config;
}

void module_restore_config(ModuleConfig *config_) {
    memcpy(&config, config_, sizeof(ModuleConfig));
}
```

**NVM Integration** ([firmware/src/nvm/nvm.c](firmware/src/nvm/nvm.c)):
```c
// In NVMStruct:
typedef struct {
    // ... existing configs ...
    ModuleConfig module_config;  // Add new config
} NVMStruct;

// In nvm_save_config():
nvm_struct.module_config = *module_get_config();

// In nvm_load_config():
module_restore_config(&nvm_struct.module_config);
```

### Pattern: Reading Firmware State (Python)

```python
# Simple attribute read
voltage = tm.Vbus
current = tm.Ibus
position = tm.encoder.position_estimate

# Nested attributes
setpoint = tm.controller.position.setpoint

# Enums/options
state = tm.controller.state
if state == 0:  # IDLE
    print("Motor is idle")
elif state == 2:  # CL_CONTROL
    print("Closed-loop control active")

# Flags/bitmasks
errors = tm.motor.errors
if errors & (1 << 4):  # Check specific bit
    print("Abnormal calibration voltage")
```

### Pattern: Writing Firmware State (Python)

```python
# Simple write
tm.controller.current.Iq_setpoint = 2.5  # amperes

# With units
from pint import UnitRegistry
ureg = UnitRegistry()
tm.controller.current.Iq_setpoint = 2.5 * ureg.ampere

# Set limits
tm.controller.velocity.limit = 100000  # ticks/s
tm.controller.current.Iq_limit = 10.0  # amperes

# Change mode
tm.controller.position_mode()  # Enter position control
tm.controller.velocity_mode()  # Enter velocity control
tm.controller.current_mode()   # Enter current control
tm.controller.idle()           # Enter idle (safe stop)
```

### Pattern: Control Loop Modification

**File**: [firmware/src/controller/controller.c](firmware/src/controller/controller.c)

```c
// Mark function for RAM execution
TM_RAMFUNC void CLControlStep(void) {
    // Read sensors
    observer_update();

    // Example: Add low-pass filter
    static float Iq_filtered = 0.0f;
    const float alpha = 0.1f;  // Filter coefficient
    float Iq_raw = ADC_get_Iq();
    Iq_filtered = alpha * Iq_raw + (1.0f - alpha) * Iq_filtered;

    // Use filtered value in control loop
    // ... rest of control algorithm ...
}
```

**Verify timing**:
```python
load = tm.scheduler.load
assert load < 3000, f"Control loop overrun: {load} cycles"
```

## Naming Conventions

### Firmware Constants

```c
// All caps with underscores
#define PWM_FREQ_HZ (20000)
#define MAX_CALIBRATION_VOLTAGE (0.5f)
#define CAL_R_LEN (2 * PWM_FREQ_HZ)

// Board-specific prefixes
#if defined BOARD_REV_R5
#define MIN_TRIP_CURRENT (5.0f)
#elif defined BOARD_REV_M5
#define MIN_TRIP_CURRENT (1.0f)
#endif
```

### Firmware Types

```c
// PascalCase for structs and enums
typedef struct {
    float phase_resistance;
    float phase_inductance;
} MotorConfig;

typedef enum {
    CONTROLLER_STATE_IDLE = 0,
    CONTROLLER_STATE_CALIBRATE = 1,
    CONTROLLER_STATE_CL_CONTROL = 2
} controller_state_options;
```

### Firmware Functions

```c
// module_action_object (lowercase with underscores)
float motor_get_temperature(void);
void controller_set_state(uint8_t state);
bool ADC_calibrate_offset(void);
```

### Python Variables

```python
# snake_case for variables and functions
current_setpoint = 2.5
position_estimate = tm.encoder.position_estimate

def calibrate_motor(current: float) -> bool:
    pass

# PascalCase for classes
class TMTestCase(unittest.TestCase):
    pass
```

## File Organization

### Firmware Module Structure

```
firmware/src/module/
├── module.h           # Public interface (typedefs, function declarations)
├── module.c           # Implementation (static state, function definitions)
└── README.md          # Module documentation (optional)
```

**Header Pattern**:
```c
#pragma once

// Forward declarations
typedef struct ModuleState ModuleState;
typedef struct ModuleConfig ModuleConfig;

// Public API
void module_init(void);
float module_get_value(void);
void module_set_value(float value);
```

**Implementation Pattern**:
```c
#include "module.h"

// Static state (module-private)
static ModuleState state = {0};
static ModuleConfig config = {0};

// Public functions
void module_init(void) {
    // Initialize module
}

float module_get_value(void) {
    return state.value;
}
```

### Python Test Structure

```python
import pytest
from tests.tm_test_case import TMTestCase

class TestFeatureName(TMTestCase):
    """Test suite for specific feature"""

    def setUp(self):
        """Setup before each test (optional)"""
        super().setUp()

    @pytest.mark.hitl_default
    def test_basic_functionality(self):
        """Test basic operation"""
        self.try_calibrate()
        # Test implementation

    @pytest.mark.hitl_default
    def test_edge_cases(self):
        """Test boundary conditions"""
        self.try_calibrate()
        # Test implementation
```

## Documentation Comments

### Firmware

```c
/**
 * @brief Estimate motor temperature from phase resistance change
 *
 * Uses the temperature coefficient of copper (0.00393/°C) to estimate
 * winding temperature based on measured resistance during operation.
 *
 * @return Estimated temperature in degrees Celsius
 *
 * @note Assumes calibration was performed at 25°C
 * @warning Accuracy degrades if motor is rapidly accelerating/decelerating
 */
float motor_get_temperature(void);
```

### Python

```python
def calibrate_motor(current: float, timeout: float = 10.0) -> bool:
    """
    Perform motor calibration sequence.

    Calibrates phase resistance, inductance, pole pairs, and encoder offset.
    Motor must be free to rotate during calibration.

    Args:
        current: Calibration current in amperes (typically 1-5A)
        timeout: Maximum time to wait for calibration completion (seconds)

    Returns:
        True if calibration succeeded, False otherwise

    Raises:
        ValueError: If current is outside safe range
        TimeoutError: If calibration exceeds timeout

    Example:
        >>> tm = create_device(node_id=1)
        >>> success = calibrate_motor(current=2.5, timeout=15.0)
        >>> if success:
        ...     print("Calibration complete")
    """
    pass
```

## References

- [ARCHITECTURE.md](ARCHITECTURE.md) - System design and module organization
- [AVLOS_GUIDE.md](AVLOS_GUIDE.md) - YAML specification details
- [SAFETY.md](SAFETY.md) - Performance and safety constraints
- [TESTING.md](TESTING.md) - Testing practices and patterns
- [CONTRIBUTING.md](CONTRIBUTING.md) - Contribution workflow

---

**Document Status**: Living document, updated as coding conventions evolve.

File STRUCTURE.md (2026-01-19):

# Tinymovr Directory Structure

**Purpose**: Quick reference to project organization and file locations.

**Target Audience**: Developers and AI agents navigating the codebase.

## Repository Organization

```
Tinymovr/
├── firmware/              # Embedded C firmware for PAC5527 MCU
├── studio/                # Python client library and tools
├── hardware/              # Hardware design files and datasheets
├── docs/                  # Sphinx documentation (user-facing)
├── avlos_config.yaml      # Code generation configuration
├── ARCHITECTURE.md        # System architecture guide
├── SAFETY.md             # Safety-critical constraints
├── AVLOS_GUIDE.md        # Protocol modification guide
├── CONVENTIONS.md        # Code style and patterns
├── TESTING.md            # Testing practices
├── CLAUDE.md             # AI agent navigation
├── CONTRIBUTING.md       # Contribution workflow
└── README.md             # Project overview
```

## Firmware Structure

### Top Level

```
firmware/
├── src/                   # Source code (17 modules)
├── pac55xx_sdk/          # Qorvo PAC55xx SDK (not in repo)
├── bootloader/           # CAN/DFU bootloader source
├── build/                # Build artifacts (.elf, .bin, .map)
├── release_binaries/     # Pre-built release binaries
├── Makefile              # Build system
├── pac55xx.ld            # Linker script (memory layout)
└── sdk_patch.patch       # SDK modifications
```

### Source Modules

```
firmware/src/
├── main.c                # Entry point, initialization
├── common.h              # Board revisions, global includes
├── config.h              # System constants, timing parameters
├── tm_enums.h            # Generated enums (from Avlos)
│
├── controller/           # FOC control loops
│   ├── controller.c      # Main control loop (20 kHz)
│   └── controller.h      # Control state and configuration
│
├── motor/                # Motor management and calibration
│   ├── motor.c           # Calibration sequences (R, L, poles)
│   └── motor.h           # Motor parameters, limits
│
├── observer/             # State estimation
│   ├── observer.c        # Position/velocity estimation
│   └── observer.h        # Observer state
│
├── sensor/               # Encoder drivers
│   ├── sensors.c         # Sensor abstraction layer
│   ├── ma7xx.c           # MPS MA7xx (onboard)
│   ├── as5047.c          # AMS AS5047 (external SPI)
│   ├── amt22.c           # CUI AMT22 (external SPI)
│   └── hall.c            # Hall effect sensors
│
├── gatedriver/           # PWM generation
│   ├── gatedriver.c      # Space Vector Modulation (SVM)
│   └── gatedriver.h      # PWM configuration
│
├── adc/                  # Current sensing
│   ├── adc.c             # ADC initialization, ISR
│   └── adc.h             # ADC channels, calibration
│
├── can/                  # CAN bus communication
│   ├── can.c             # CAN driver, message handling
│   ├── can.h             # CAN configuration
│   ├── can_endpoints.c   # Generated Avlos endpoints
│   └── can_endpoints.h   # Generated Avlos declarations
│
├── uart/                 # UART communication (alternative)
│   ├── uart.c            # UART driver
│   └── uart.h            # UART configuration
│
├── ssp/                  # SPI/SSP peripheral
│   ├── ssp.c             # SPI driver for external encoders
│   └── ssp.h             # SPI configuration
│
├── nvm/                  # Non-volatile memory (flash)
│   ├── nvm.c             # Configuration persistence
│   └── nvm.h             # NVM structure
│
├── system/               # Platform-level services
│   ├── system.c          # Clock config, reset, voltage monitoring
│   └── system.h          # System state
│
├── scheduler/            # Timing and synchronization
│   ├── scheduler.c       # Control loop synchronization
│   └── scheduler.h       # Scheduler state, load monitoring
│
├── watchdog/             # Communication timeout
│   ├── watchdog.c        # Watchdog timer management
│   └── watchdog.h        # Watchdog configuration
│
├── timer/                # Hardware timers
│   ├── timer.c           # PWM timer setup
│   └── timer.h           # Timer configuration
│
├── utils/                # Math utilities
│   ├── utils.c           # Fast trig, SVM algorithm
│   └── utils.h           # Utility functions
│
└── rtt/                  # SEGGER RTT debug output
    ├── SEGGER_RTT.c      # RTT implementation
    └── SEGGER_RTT.h      # RTT interface
```

### Key Firmware Files

| File | Purpose |
|---|---|
| [firmware/src/main.c](firmware/src/main.c) | Entry point, startup sequence |
| [firmware/src/common.h](firmware/src/common.h) | Board revision defines, includes |
| [firmware/src/config.h](firmware/src/config.h) | Timing, PWM frequency, limits |
| [firmware/src/controller/controller.c](firmware/src/controller/controller.c) | Main control loop (20 kHz) |
| [firmware/src/motor/motor.c](firmware/src/motor/motor.c) | Calibration implementation |
| [firmware/src/motor/motor.h](firmware/src/motor/motor.h) | Calibration constants, motor limits |
| [firmware/src/can/can_endpoints.c](firmware/src/can/can_endpoints.c) | Generated Avlos endpoints (97 endpoints) |
| [firmware/src/tm_enums.h](firmware/src/tm_enums.h) | Generated enums (states, errors, options) |
| [firmware/Makefile](firmware/Makefile) | Build system (REV=R52, debug/release) |
| [firmware/pac55xx.ld](firmware/pac55xx.ld) | Memory layout (128KB flash, 32KB RAM) |

## Studio Structure

### Top Level

```
studio/Python/
├── tinymovr/             # Main package
├── tests/                # Test suite (HITL and simulation)
├── scripts/              # Utility scripts
├── setup.py              # Package installation
└── package.json          # Node.js dependencies (GUI)
```

### Package Structure

```
studio/Python/tinymovr/
├── __init__.py           # Package initialization
├── __main__.py           # CLI entry point
│
├── specs/                # YAML API specifications (Avlos)
│   ├── tinymovr_1_3_x.yaml
│   ├── tinymovr_2_0_x.yaml
│   ├── tinymovr_2_1_x.yaml
│   ├── tinymovr_2_2_x.yaml
│   └── tinymovr_2_3_x.yaml  # Current version
│
├── config/               # Configuration and spec loading
│   ├── config.py         # Spec loading, hash matching, device discovery
│   └── __init__.py
│
├── codec/                # Binary serialization
│   ├── codec.py          # Multibyte codec for CAN messages
│   └── __init__.py
│
├── bus_router.py         # Global singleton, message distribution
├── bus_manager.py        # CAN bus connection, auto-reconnect
├── channel.py            # Per-device communication channel
├── device_discovery.py   # Automatic device detection via heartbeat
├── constants.py          # Constants (node IDs, timeouts)
│
├── gui/                  # Qt-based graphical interface
│   ├── main.py           # GUI entry point
│   ├── widgets/          # Custom widgets
│   └── resources/        # Icons, stylesheets
│
└── resources/            # Package resources
    └── schema.json       # JSON schema for validation
```

### Test Structure

```
studio/Python/tests/
├── tm_test_case.py       # Base class for HITL tests
├── test_simulation.py    # Simulation tests (no hardware)
├── test_board.py         # Core HITL tests
├── test_sensors.py       # Sensor-specific tests
├── test_homing.py        # Homing feature tests
├── test_trajectory.py    # Trajectory planner tests
└── test_eol.py          # End-of-line comprehensive tests
```

### Key Studio Files

| File | Purpose |
|---|---|
| [studio/Python/tinymovr/specs/tinymovr_2_3_x.yaml](studio/Python/tinymovr/specs/tinymovr_2_3_x.yaml) | Current API specification |
| [studio/Python/tinymovr/config/config.py](studio/Python/tinymovr/config/config.py) | Spec loading and hash matching |
| [studio/Python/tinymovr/bus_router.py](studio/Python/tinymovr/bus_router.py) | Message routing singleton |
| [studio/Python/tinymovr/channel.py](studio/Python/tinymovr/channel.py) | Per-device CAN channel |
| [studio/Python/tests/tm_test_case.py](studio/Python/tests/tm_test_case.py) | Base class for HITL tests |
| [studio/Python/setup.py](studio/Python/setup.py) | Package installation config |

## Hardware Structure

```
hardware/
├── R5/                   # R5.x series boards (high-current)
│   ├── R50/              # R5.0 design files
│   ├── R51/              # R5.1 design files
│   ├── R52/              # R5.2 design files
│   └── R53/              # R5.3 design files
│
├── M5/                   # M5.x series boards (gimbal)
│   └── M51/              # M5.1 design files
│
├── R3/                   # R3.x series boards (legacy)
│   ├── R32/              # R3.2 design files
│   └── R33/              # R3.3 design files
│
├── Actuator/             # Complete actuator designs
├── ServoKit/             # Development/testing hardware
├── Datasheets/           # MCU and component datasheets
│   ├── PAC5527 Data Sheet.pdf
│   └── UG_PAC5527.pdf
│
└── misc/                 # Miscellaneous hardware files
```

## Documentation Structure

```
docs/
├── index.rst             # Documentation home
├── conf.py               # Sphinx configuration
│
├── hardware/             # Hardware documentation
│   ├── board_versions.rst
│   └── specifications.rst
│
├── control/              # Control theory and tuning
│   ├── position_control.rst
│   ├── velocity_control.rst
│   └── current_control.rst
│
├── features/             # Feature guides
│   ├── calibration.rst
│   ├── homing.rst
│   └── trajectory.rst
│
├── protocol/             # Communication protocol
│   ├── overview.rst
│   └── reference.rst     # Generated from Avlos
│
├── studio/               # Python client usage
│   ├── installation.rst
│   └── quickstart.rst
│
├── develop/              # Developer guides
│   ├── firmware.rst
│   └── python.rst
│
└── interfaces/           # Interface guides
    ├── can.rst
    └── uart.rst
```

## Code Generation Files

| File | Purpose |
|---|---|
| [avlos_config.yaml](avlos_config.yaml) | Avlos code generation configuration |
| [studio/Python/tinymovr/specs/tinymovr_2_3_x.yaml](studio/Python/tinymovr/specs/tinymovr_2_3_x.yaml) | API specification (input) |
| [firmware/src/can/can_endpoints.c](firmware/src/can/can_endpoints.c) | Generated C implementation |
| [firmware/src/can/can_endpoints.h](firmware/src/can/can_endpoints.h) | Generated C header |
| [firmware/src/tm_enums.h](firmware/src/tm_enums.h) | Generated enums |
| [docs/protocol/reference.rst](docs/protocol/reference.rst) | Generated documentation |

**Workflow**:
```bash
avlos from file <spec_file>.yaml
```

## Build Artifacts

### Firmware Build

```
firmware/build/
├── tinymovr_fw.elf       # Executable with debug symbols
├── tinymovr_fw.bin       # Binary for flashing
├── tinymovr_fw.map       # Memory map
└── *.o                   # Object files
```

### Python Build

```
studio/Python/
├── dist/                 # Wheel and source distribution
│   ├── tinymovr-X.Y.Z-py3-none-any.whl
│   └── tinymovr-X.Y.Z.tar.gz
└── tinymovr.egg-info/    # Package metadata
```

## Ignored Directories

Not tracked in version control (see `.gitignore`):

```
firmware/pac55xx_sdk/     # PAC55xx SDK (copyright restrictions)
firmware/build/           # Build artifacts
studio/Python/dist/       # Python distribution packages
studio/Python/*.egg-info/ # Python package metadata
venv/                     # Python virtual environment
docs/_build/              # Sphinx build output
__pycache__/              # Python bytecode cache
.vscode/                  # Editor settings
.DS_Store                 # macOS metadata
```

## Quick Navigation by Task

### Modifying Control Loop
- Start: [firmware/src/controller/controller.c](firmware/src/controller/controller.c)
- Check: [SAFETY.md](SAFETY.md) for constraints

### Adding API Endpoint
- Edit: [studio/Python/tinymovr/specs/tinymovr_2_3_x.yaml](studio/Python/tinymovr/specs/tinymovr_2_3_x.yaml)
- Generate: `avlos from file <spec_file>.yaml`
- Implement: Appropriate module in `firmware/src/`

### Modifying Calibration
- Edit: [firmware/src/motor/motor.c](firmware/src/motor/motor.c)
- Check: [firmware/src/motor/motor.h](firmware/src/motor/motor.h) for constants

### Writing Tests
- HITL: [studio/Python/tests/test_board.py](studio/Python/tests/test_board.py)
- Simulation: [studio/Python/tests/test_simulation.py](studio/Python/tests/test_simulation.py)
- Base class: [studio/Python/tests/tm_test_case.py](studio/Python/tests/tm_test_case.py)

### Adding Board Revision
- Edit: [firmware/src/common.h](firmware/src/common.h)
- Update: [firmware/Makefile](firmware/Makefile)

## References

- [ARCHITECTURE.md](ARCHITECTURE.md) - System design and module responsibilities
- [CONVENTIONS.md](CONVENTIONS.md) - Code style and patterns
- [AVLOS_GUIDE.md](AVLOS_GUIDE.md) - Protocol modification workflow
- [TESTING.md](TESTING.md) - Testing practices

---

**Document Status**: Living document, updated as project structure evolves.

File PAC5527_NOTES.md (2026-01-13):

# PAC5527 MCU Architecture Notes

## Overview

The **Qorvo PAC5527** is a specialized motor control System-on-Chip (SoC) featuring an ARM Cortex-M4F core with integrated power stage and motor control peripherals. This document extracts key architectural information from the PAC5527 datasheets and describes how Tinymovr leverages the MCU's capabilities.

**Note**: The full PAC5527 datasheets are not included in version control due to copyright restrictions. When available, they can be found at:
- `hardware/Datasheets/PAC5527 Data Sheet.pdf`
- `hardware/Datasheets/UG_PAC5527.pdf`

## Core Processor

### ARM Cortex-M4F Specifications
- **Architecture**: ARMv7E-M with DSP extensions
- **Core Frequency**: 150 MHz (HCLK_FREQ_HZ)
- **FPU**: Single-precision floating-point unit (FPv4-SP-D16)
- **Instruction Set**: Thumb-2 with hardware multiply and divide
- **NVIC**: Nested Vector Interrupt Controller with 16 priority levels
- **MPU**: Memory Protection Unit (optional, not used in Tinymovr)

**Reference**: [firmware/src/config.h](firmware/src/config.h#L22-L25)
```c
#define ACLK_FREQ_HZ    (300000000)  // Peripheral clock
#define HCLK_FREQ_HZ    (150000000)  // CPU clock
#define CLKREF_FREQ_HZ  (4000000)    // Reference clock
```

### Clock Architecture
- **ACLK (Peripheral Clock)**: 300 MHz - Drives PWM timers and ADC
- **HCLK (CPU Clock)**: 150 MHz - ARM Cortex-M4F core
- **FRCLK (Free-Running Clock)**: 4 MHz - Reference for timing
- **PLL**: On-chip PLL generates high-speed clocks from external crystal/oscillator

## Memory Architecture

### Flash Memory
- **Total Size**: 128 KB (0x00020000 bytes)
- **Bootloader Region**: 4 KB at 0x00000000 - 0x00001000
- **Application Region**: 124 KB at 0x00001000 - 0x00020000
- **Flash Wait States**: Automatically inserted for high-frequency access
- **Endurance**: Typical 10,000 erase/write cycles
- **Data Retention**: 20+ years at 85°C

**Reference**: [firmware/pac55xx.ld](firmware/pac55xx.ld#L3-L9)
```ld
MEMORY
{
    rom0 (rx) : ORIGIN = 0x00000000, LENGTH = 0x00001000  /* Bootloader */
    rom (rx)  : ORIGIN = 0x00001000, LENGTH = 0x0001F000  /* Application */
    ram (rwx) : ORIGIN = 0x20000000, LENGTH = 0x00007F00  /* Main RAM */
    SHARED (rwx) : ORIGIN = 0x20007F00, LENGTH = 0x00000100  /* Bootloader shared */
}
```

### RAM Memory
- **Total Size**: 32 KB (0x00008000 bytes)
- **Main RAM**: 31.75 KB (0x20000000 - 0x20007F00) - Application use
- **Shared Region**: 256 bytes (0x20007F00 - 0x20008000) - Bootloader communication
- **Zero Wait State**: All RAM accesses complete in single cycle
- **Retention Mode**: Low-power RAM retention available

### RAM Execution Optimization
Critical real-time functions execute from RAM to avoid flash wait states:

**Reference**: [firmware/src/common.h](firmware/src/common.h#L67-L74)
```c
#if defined(DEBUG)
#define TM_RAMFUNC
#elif defined (NDEBUG)
#define TM_RAMFUNC PAC5XXX_RAMFUNC  // Copy function to RAM at startup
#endif
```

Functions marked `TM_RAMFUNC` are copied to RAM during initialization and execute with zero wait states, critical for maintaining 20 kHz control loop timing.

### Bootloader Integration
The bootloader resides in the first 4 KB of flash and provides DFU (Device Firmware Update) capability:

**Trigger Patterns** ([firmware/src/common.h](firmware/src/common.h#L76-L77)):
```c
#define BTL_TRIGGER_PATTERN      0x39          // Flash-based trigger
#define BTL_TRIGGER_PATTERN_RAM  0x5048434D    // RAM-based trigger ("HPCM")
```

The shared RAM region at 0x20007F00 allows the application to pass parameters to the bootloader before reset.

## Motor Control Peripherals

### 3-Phase PWM Generation
The PAC5527 integrates specialized timer peripherals for 3-phase motor control:

- **PWM Frequency**: 20 kHz (50 μs period) - Configured in [firmware/src/config.h](firmware/src/config.h#L31)
- **Resolution**: 16-bit counters provide sub-microsecond duty cycle resolution
- **Dead-Time Insertion**: Hardware dead-time generation prevents shoot-through
- **Center-Aligned Mode**: Reduces current ripple and EMI
- **Complementary Outputs**: Automatic generation of high/low-side gate signals

### Integrated Gate Drivers
The PAC5527 includes on-chip gate drivers for 6 external MOSFETs (3 half-bridges):

- **Driver Supply**: Integrated charge pump for high-side gate drive
- **Current Capability**: Sufficient for typical power MOSFETs
- **Protection**: Overcurrent, overvoltage, and thermal shutdown
- **Status Monitoring**: Fault detection with interrupt capability

### ADC (Analog-to-Digital Converter)
The PAC5527 features a high-speed ADC optimized for motor control:

- **Resolution**: 12-bit successive approximation (SAR)
- **Sampling Rate**: Up to 1 MSPS
- **Channels**: Multiple input channels for current, voltage, and temperature sensing
- **Trigger Modes**: Hardware-triggered from PWM timer for synchronous sampling
- **DMA Support**: Direct memory access for zero-CPU-overhead sampling

**Tinymovr Usage**:
- **Phase Current Sensing**: Samples A, B, C phase currents at PWM frequency (20 kHz)
- **Bus Voltage Monitoring**: Continuous Vbus measurement for FOC calculations
- **Temperature Sensing**: Internal die temperature sensor

The ADC interrupt at 20 kHz drives the main control loop. See [firmware/src/controller/controller.c](firmware/src/controller/controller.c) for the control loop implementation.

### Current Sensing Architecture
The PAC5527 integrates current sense amplifiers for shunt resistor measurement:

- **Amplifier Gain**: Programmable gain for different shunt resistor values
- **Offset Calibration**: Automatic offset calibration during startup
- **Noise Performance**: Low-noise design for accurate current measurement

**Board-Specific Shunt Resistors**:
- **R3.x/R5.x Boards**: Lower resistance shunts for high-current motors
- **M5.x Boards**: Higher resistance shunts for gimbal motors (lower current)

Trip current thresholds vary by board revision ([firmware/src/common.h](firmware/src/common.h#L129-L133)):
```c
#if defined BOARD_REV_R3 || defined BOARD_REV_R5
#define MIN_TRIP_CURRENT (5.0f)  // A
#elif defined BOARD_REV_M5
#define MIN_TRIP_CURRENT (1.0f)  // A
#endif
```

## Communication Peripherals

### CAN 2.0B Controller
The PAC5527 includes a full CAN 2.0B controller with the following features:

- **Standard**: ISO 11898-1 CAN 2.0B
- **Bit Rates**: Up to 1 Mbps (Tinymovr default: 1 Mbps)
- **ID Support**: 11-bit standard and 29-bit extended identifiers
- **Message Objects**: Multiple hardware message buffers (typically 32)
- **Acceptance Filtering**: Hardware ID filtering to reduce CPU load
- **Error Handling**: Automatic error detection, error counters, and bus-off recovery

**Tinymovr CAN Configuration**:
- **Extended ID**: 29-bit arbitration ID structure
- **Node ID**: 8-bit device address (configurable 1-255)
- **Protocol Hash**: 9-bit protocol version identifier
- **Endpoint ID**: 12-bit endpoint address (97 total endpoints)

**Pin Assignments by Board Revision** ([firmware/src/common.h](firmware/src/common.h#L103-L109)):
```c
#if defined BOARD_REV_R3
#define CAN_PE23        // Pins PE2 (TX), PE3 (RX)
#elif defined BOARD_REV_R5
#define CAN_PF67        // Pins PF6 (TX), PF7 (RX)
#elif defined BOARD_REV_M5
#define CAN_PD56        // Pins PD5 (TX), PD6 (RX)
#endif
```

### UART (Universal Asynchronous Receiver/Transmitter)
- **Baud Rates**: Up to 1 Mbps (Tinymovr uses 115200 baud)
- **Data Format**: 8N1 (8 data bits, no parity, 1 stop bit)
- **FIFO**: Hardware TX/RX FIFOs reduce interrupt overhead
- **Interrupt Support**: TX empty, RX available, error detection

**Reference**: [firmware/src/config.h](firmware/src/config.h#L49-L51)
```c
#define UART_ENUM UARTB           // UART peripheral selection
#define UART_REF PAC55XX_UARTB    // Hardware register base
#define UART_BAUD_RATE (115200)   // Default baud rate
```

**Note**: UART is primarily used for firmware updates and debugging. CAN bus is the primary communication interface during normal operation.

### SSP/SPI (Synchronous Serial Port)
The PAC5527 provides SSP peripherals for SPI communication with external sensors:

- **Modes**: SPI Master and Slave modes
- **Clock Rates**: Up to 12 Mbps (HCLK/4)
- **Data Width**: Configurable 4-16 bits per transfer
- **DMA Support**: Reduces CPU overhead for bulk transfers

**Tinymovr Usage**:
Communicates with external encoders:
- **MA7xx**: MPS magnetic encoders (1.5-12 Mbps)
- **AS5047**: AMS magnetic encoder (SPI)
- **AMT22**: CUI absolute encoder (SPI)

See [firmware/src/sensor/](firmware/src/sensor/) for encoder driver implementations.

## Unique Device Identification

The PAC5527 provides a 96-bit unique device ID burned during manufacturing:

**Reference**: [firmware/src/system/system.h](firmware/src/system/system.h#L51-L54)
```c
static inline uint32_t system_get_uid(void)
{
    // XOR three 32-bit words to create unique 32-bit ID
    return PAC55XX_INFO1->UNIQUEID[0] ^
           PAC55XX_INFO1->UNIQUEID[1] ^
           PAC55XX_INFO1->UNIQUEID[2];
}
```

This UID is:
- **Factory Programmed**: Unique to each PAC55xx chip produced
- **Read-Only**: Cannot be modified by application code
- **Use Cases**: Device identification, serial number generation, encryption seeds

## Board Revision Support

Tinymovr firmware supports multiple board revisions through compile-time configuration:

**Reference**: [firmware/src/common.h](firmware/src/common.h#L93-L127)
```c
// Top-level revision families
#if defined BOARD_REV_R32 || defined BOARD_REV_R33
#define BOARD_REV_R3
#elif defined BOARD_REV_R50 || BOARD_REV_R51 || defined BOARD_REV_R52 || defined BOARD_REV_R53
#define BOARD_REV_R5
#elif defined BOARD_REV_M51
#define BOARD_REV_M5
#endif

// Specific revision indices
#define BOARD_REV_IDX   // R32=2, R33=3, R50=10, R51=11, R52=12, R53=13, M51=21
```

**Board Characteristics**:
- **R3.x**: Original high-current design (CAN on PE2/PE3)
- **R5.x**: Updated design with improved layout (CAN on PF6/PF7)
- **M5.x**: Gimbal motor variant with lower current (CAN on PD5/PD6)

**Build Command Example**:
```bash
make release REV=R52   # Builds for R5.2 board
make release REV=M51   # Builds for M5.1 board
```

## Power Management Features

### Supply Monitoring
- **Vbus Monitoring**: Continuous bus voltage measurement via ADC
- **Undervoltage Lockout (UVLO)**: Protection against low supply voltage
- **Overvoltage Protection**: Shuts down drivers if Vbus exceeds safe limits

**Threshold** ([firmware/src/config.h](firmware/src/config.h#L38)):
```c
#define VBUS_LOW_THRESHOLD  (10.4f)  // V - Minimum operating voltage
```

### Charge Pump
The integrated charge pump provides gate drive voltage for high-side MOSFETs:

- **Output Voltage**: Vbus + 10V (typical)
- **Fault Detection**: Charge pump fault signals monitored by firmware
- **Warnings**: Charge pump faults trigger system warnings

### Temperature Monitoring
- **Die Temperature Sensor**: Internal ADC channel for MCU temperature
- **Thermal Shutdown**: Hardware protection at extreme temperatures
- **Application Monitoring**: Firmware can read die temperature via `tm.temp`

**Reference**: [studio/Python/tinymovr/specs/tinymovr_2_3_x.yaml](studio/Python/tinymovr/specs/tinymovr_2_3_x.yaml) (lines 38-42)

## Watchdog Timer (WWDT)

The PAC5527 includes a windowed watchdog timer for fault detection:

- **Window Mode**: Must be refreshed within specific time window
- **Reset on Timeout**: Generates system reset if not serviced
- **Configuration**: Programmable timeout period

**Tinymovr Usage**:
Detects communication loss and resets to safe IDLE state. See [firmware/src/watchdog/](firmware/src/watchdog/) for implementation.

## Debug and Programming Interface

### JTAG/SWD
The PAC5527 supports ARM Serial Wire Debug (SWD) for programming and debugging:

- **Pins**: SWDIO, SWCLK (standard ARM Cortex-M debug interface)
- **Debugger Support**: J-Link, ST-Link, CMSIS-DAP compatible
- **Breakpoints**: 6 hardware breakpoints, unlimited software breakpoints
- **Watchpoints**: 4 hardware data watchpoints

**J-Link Configuration**: [firmware/JLinkDevices.xml](firmware/JLinkDevices.xml)

### SEGGER RTT (Real-Time Transfer)
The firmware includes optional RTT support for printf-style debugging:

- **Zero Overhead**: Does not halt CPU for output
- **High Speed**: Much faster than UART
- **Bidirectional**: Supports input and output
- **Implementation**: [firmware/src/rtt/](firmware/src/rtt/)

## PAC55xx SDK Structure

The Qorvo PAC55xx SDK provides hardware abstraction layers:

**Location**: [firmware/pac55xx_sdk/](firmware/pac55xx_sdk/) (not in repo, download from Qorvo)

**SDK Components**:
- `device/`: Chip-specific headers (pac5527.h, system_pac5xxx.h)
- `peripheral/`: Peripheral register definitions (pac5xxx_*.h)
- `driver/`: Driver functions (pac5xxx_driver_*.h)

**Important Notes**:
1. The SDK is **not included** in the Tinymovr repository due to Qorvo licensing restrictions
2. Developers must **download** from Qorvo website (requires registration)
3. A **patch** must be applied: [firmware/sdk_patch.patch](firmware/sdk_patch.patch)
4. Apply patch: `python3 -m patch sdk_patch.patch`

**SDK Includes** ([firmware/src/common.h](firmware/src/common.h#L28-L54)):
```c
#include "pac5xxx.h"              // Core chip definitions
#include "pac5xxx_adc.h"          // ADC peripheral
#include "pac5xxx_can.h"          // CAN peripheral
#include "pac5xxx_timers.h"       // PWM timers
#include "pac5xxx_uart.h"         // UART peripheral
#include "pac5xxx_ssp.h"          // SPI/SSP peripheral
// ... additional peripheral headers
```

## Performance Characteristics

### Timing Budget (20 kHz Control Loop)
- **Loop Period**: 50 μs (1 / 20 kHz)
- **CPU Cycles Available**: 7,500 cycles @ 150 MHz
- **Target Usage**: <3,000 cycles (40%) for control algorithm
- **Overhead**: Interrupts, context switches, ADC sampling

**Monitoring**: `tm.scheduler.load` reports actual cycle count per iteration

### Interrupt Priorities
The NVIC priority scheme (higher value = lower priority):
1. **ADC IRQ** (Highest): 20 kHz control loop trigger
2. **CAN IRQ**: Asynchronous message reception
3. **UART IRQ**: Asynchronous message reception
4. **SysTick**: 1 kHz system timing
5. **Watchdog IRQ**: Safety timeout handling

## Key Design Constraints

### Real-Time Requirements
- Control loop **must complete** in <50 μs (leaves 10 μs margin)
- Functions in control path **must be** RAM-resident (TM_RAMFUNC)
- Avoid dynamic memory allocation (malloc/free) in real-time code
- Disable interrupts only for critical sections (<1 μs)

### Float Precision
- ARM Cortex-M4F has **single-precision** FPU only
- All floating-point variables are `float` (32-bit), not `double` (64-bit)
- Double-precision math falls back to software emulation (very slow)

### Hardware Limitations
- **No Hardware Division**: Integer division uses software routine (expensive)
- **No RTOS**: Bare-metal firmware with cooperative scheduling
- **Limited RAM**: 32 KB total, must be carefully managed
- **Flash Endurance**: Limit configuration writes to extend flash lifetime

## References

### Firmware Files
- [firmware/src/common.h](firmware/src/common.h) - Core definitions and PAC55xx includes
- [firmware/src/config.h](firmware/src/config.h) - System configuration constants
- [firmware/src/system/system.h](firmware/src/system/system.h) - System initialization
- [firmware/pac55xx.ld](firmware/pac55xx.ld) - Linker script with memory layout
- [firmware/Makefile](firmware/Makefile) - Build system with board revision selection

### Hardware
- `hardware/Datasheets/PAC5527 Data Sheet.pdf` - Full datasheet (when available)
- `hardware/Datasheets/UG_PAC5527.pdf` - User guide (when available)
- [hardware/R5/](hardware/R5/) - R5.x board designs
- [hardware/M5/](hardware/M5/) - M5.x board designs

### External Resources
- **Qorvo Website**: https://www.qorvo.com (SDK download, datasheets)
- **ARM Cortex-M4**: https://developer.arm.com/ip-products/processors/cortex-m/cortex-m4
- **CMSIS**: [firmware/cmsis_core/core_cm4.h](firmware/cmsis_core/core_cm4.h)

---

**Document Status**: Living document, updated as firmware evolves.
**Last Major Update**: Based on firmware v2.3.x with calibration voltage debouncing fix.

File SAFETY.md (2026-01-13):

# Tinymovr Safety-Critical Constraints

## Overview

Tinymovr controls high-power electric motors capable of causing physical harm if misused. This document outlines **safety-critical constraints** that must be understood and respected when modifying firmware, especially the control loop and motor calibration systems.

**Violating these constraints can result in**:
- Motor runaway or uncontrolled motion
- Overheating and fire hazard
- Mechanical damage to equipment
- Electrical damage to the controller
- Personal injury

## ⚠️ Real-Time Constraints

### Control Loop Timing

**Hard Requirement**: The control loop **must complete** in less than 50 μs (microseconds).

**Reference**: [firmware/src/config.h](firmware/src/config.h#L31-L32)
```c
#define PWM_FREQ_HZ (20000)  // 20 kHz = 50 μs period
```

**Timing Budget**:
- **Period**: 50 μs (1 / 20 kHz)
- **CPU Cycles**: 7,500 cycles @ 150 MHz
- **Target Usage**: <3,000 cycles (40%) for control algorithm
- **Maximum Allowed**: <5,000 cycles (67%) including overhead
- **Overhead**: Interrupts, ADC sampling, context switches

**Monitoring**: Check actual timing via `tm.scheduler.load`:
```python
load = tm.scheduler.load  # CPU cycles per control loop iteration
print(f"Control loop load: {load} cycles ({load/7500*100:.1f}%)")
```

**Reference**: [firmware/src/scheduler/scheduler.h](firmware/src/scheduler/scheduler.h#L27)

### Critical Functions Must Be RAM-Resident

Functions called from the control loop **must** be marked `TM_RAMFUNC` to avoid flash wait states.

**Reference**: [firmware/src/common.h](firmware/src/common.h#L67-L74)
```c
#if defined(DEBUG)
#define TM_RAMFUNC
#elif defined (NDEBUG)
#define TM_RAMFUNC PAC5XXX_RAMFUNC  // Copy function to RAM at startup
#endif
```

**Why**: Flash memory has wait states at 150 MHz. RAM access is zero-wait-state, ensuring deterministic timing.

**Examples of Critical Functions**:
- `CLControlStep()` - Main control loop ([firmware/src/controller/controller.c](firmware/src/controller/controller.c))
- `observer_update()` - State estimation
- `ADC_update()` - Current measurement
- `sensor_update()` - Encoder reading

**Rule**: If a function is called every 50 μs (20 kHz), it **must** be `TM_RAMFUNC`.

### Blocking Operations Forbidden

**Never** perform blocking operations in the control loop or ISRs:

❌ **Forbidden**:
- `delay()` or busy-wait loops
- `printf()` or UART output
- Dynamic memory allocation (`malloc`, `free`)
- Floating-point division (slow on Cortex-M4F)
- Large loops (>100 iterations)

✓ **Allowed**:
- Simple arithmetic (`+`, `-`, `*`)
- Fast approximations (`fast_sin()`, `fast_cos()`)
- Lookup tables
- Conditional branches (if/else)

### Interrupt Priorities

**Reference**: NVIC priority configuration (lower number = higher priority)

1. **ADC IRQ** (Highest) - Triggers control loop at 20 kHz
2. **CAN IRQ** - Asynchronous message handling
3. **UART IRQ** - Asynchronous message handling
4. **SysTick** - 1 kHz system timing
5. **Watchdog IRQ** - Safety timeout

**Rule**: Do not reconfigure interrupt priorities without understanding the impact on control loop timing.

## 🔥 Current Limits

### Board-Specific Trip Thresholds

Current limits vary by board revision due to different shunt resistors and power stages:

**Reference**: [firmware/src/common.h](firmware/src/common.h#L129-L133)
```c
#if defined BOARD_REV_R3 || defined BOARD_REV_R5
#define MIN_TRIP_CURRENT (5.0f)  // A
#elif defined BOARD_REV_M5
#define MIN_TRIP_CURRENT (1.0f)  // A
#endif
```

**Board Characteristics**:
| Board | Min Trip Current | Typical Max Current | Target Application |
|---|---|---|---|
| R3.x  | 5.0 A | 30 A peak | High-current motors |
| R5.x  | 5.0 A | 30 A peak | High-current motors |
| M5.x  | 1.0 A | 10 A peak | Gimbal motors |

### Trip Margin

The controller automatically trips to IDLE state if current exceeds 1.5× the configured limit:

**Reference**: [firmware/src/config.h](firmware/src/config.h#L37) and [firmware/src/controller/controller.c](firmware/src/controller/controller.c#L115)
```c
#define I_TRIP_MARGIN (1.5f)

// In control loop:
const float Iq_trip = our_fmaxf(config.I_limit * I_TRIP_MARGIN, MIN_TRIP_CURRENT);
if (our_fabsf(Iq) > Iq_trip)
{
    state.errors |= CONTROLLER_ERRORS_CURRENT_LIMIT_EXCEEDED;
}
```

**Example**:
- User sets `tm.controller.current.Iq_limit = 10.0` (amperes)
- Trip threshold = 10.0 × 1.5 = 15.0 A
- If Iq exceeds 15.0 A, controller enters IDLE state with error flag

### Hard Current Limit

An absolute maximum current limit protects against misconfiguration:

**Reference**: [firmware/src/config.h](firmware/src/config.h#L40)
```c
#define I_HARD_LIMIT (60.0f)  // A - Absolute maximum
```

**Rule**: Never set `I_limit` above this value. The hardware may be damaged.

### Default Current Limits by Board

**Reference**: [firmware/src/controller/controller.c](firmware/src/controller/controller.c#L73-L105)

**R3.x / R5.x Boards**:
```c
static ControllerConfig config = {
    .I_limit = 10.0f,  // Default: 10 A continuous
    // ...
};
```

**M5.x Boards**:
```c
static ControllerConfig config = {
    .I_limit = 4.0f,  // Default: 4 A continuous
    // ...
};
```

## ⚡ Voltage Monitoring

### Undervoltage Protection

The controller monitors bus voltage and enters IDLE if voltage drops below threshold:

**Reference**: [firmware/src/config.h](firmware/src/config.h#L38)
```c
#define VBUS_LOW_THRESHOLD (10.4f)  // V
```

**Why**: Low voltage can cause:
- Erratic motor behavior
- Controller brownout and reset
- Incomplete PWM cycles

**Recommendation**: Operate above 12V for stability.

### Calibration Voltage Limits

During resistance and inductance calibration, applied voltage is limited to safe values:

**Reference**: [firmware/src/motor/motor.h](firmware/src/motor/motor.h#L25-L38)

**R3.x / R5.x Boards**:
```c
#define MAX_CALIBRATION_VOLTAGE (0.5f)  // V
#define MIN_CALIBRATION_CURRENT (0.2f)  // A
```

**M5.x Boards**:
```c
#define MAX_CALIBRATION_VOLTAGE (5.0f)  // V
#define MIN_CALIBRATION_CURRENT (0.05f)  // A
```

**Why Different Values?**:
- **High-current motors** (R3/R5): Low resistance requires low voltage
- **Gimbal motors** (M5): High resistance requires higher voltage

### Calibration Voltage Debouncing (Recent Fix)

Power line noise can cause false `ABNORMAL_CALIBRATION_VOLTAGE` errors. The firmware now includes warm-up and debouncing:

**Reference**: [firmware/src/motor/motor.h](firmware/src/motor/motor.h#L56-L57)
```c
#define CAL_R_WARMUP_ITERATIONS (1500u)   // ~75ms warm-up at 20kHz
#define CAL_R_ABNORMAL_DEBOUNCE (300u)    // ~15ms debounce at 20kHz
```

**Behavior**:
1. **Warm-up Phase**: First 75ms (1500 iterations) ignored to allow voltage stabilization
2. **Debounce Window**: Voltage must exceed threshold for 15ms (300 iterations) to trigger fault
3. **Genuine Faults**: Shorts, open circuits, or wrong motor still detected

**Commit**: Added in commit `426ab7e` - "fix: Add debouncing and warm-up to resistance calibration voltage check"

## 🛡️ State Machine Safety

### State Transitions

The controller operates in three states:

**Reference**: [firmware/src/tm_enums.h](firmware/src/tm_enums.h) (generated from YAML)
```c
typedef enum
{
    CONTROLLER_STATE_IDLE = 0,       // Safe state, motors off
    CONTROLLER_STATE_CALIBRATE = 1,  // Calibration sequence
    CONTROLLER_STATE_CL_CONTROL = 2  // Closed-loop control active
} controller_state_options;
```

### Automatic Error Recovery

**Critical Safety Feature**: Errors automatically force transition to IDLE state:

**Reference**: [firmware/src/controller/controller.c](firmware/src/controller/controller.c#L120-L123)
```c
if (errors_exist() && (state.state != CONTROLLER_STATE_IDLE))
{
    controller_set_state(CONTROLLER_STATE_IDLE);
}
```

**Error Sources**:
- `CONTROLLER_ERRORS_CURRENT_LIMIT_EXCEEDED` - Overcurrent
- `MOTOR_ERRORS_ABNORMAL_CALIBRATION_VOLTAGE` - Calibration fault
- `ERRORS_UNDERVOLTAGE` - Low bus voltage
- Watchdog timeout
- Pre-control current standard deviation too high

**Rule**: Never disable automatic error transitions. This is a critical safety mechanism.

### Pre-Control Warmup

Before entering closed-loop control, the controller validates current sensor noise:

**Reference**: [firmware/src/controller/controller.c](firmware/src/controller/controller.c#L145-L150) and [firmware/src/config.h](firmware/src/config.h#L41-L42)
```c
#define MAX_CL_INIT_STEPS (200)    // Warmup iterations
#define PRE_CL_I_SD_MAX (0.4f)     // Max current standard deviation (A)

// In control loop:
if ((motor_get_is_gimbal() == false) && pre_cl_stats.size < MAX_CL_INIT_STEPS)
{
    CLPreStep();  // Collect statistics
}
```

**Why**: High current sensor noise indicates:
- Loose connections
- Electromagnetic interference
- Faulty hardware

**Behavior**: If standard deviation exceeds `PRE_CL_I_SD_MAX`, error `CONTROLLER_ERRORS_PRE_CL_I_SD_EXCEEDED` is raised and control is aborted.

## 🎯 Calibration Safety

### Multi-Stage Calibration Sequence

Calibration proceeds in strict order. Failure at any stage aborts the sequence:

**Reference**: [firmware/src/controller/controller.c](firmware/src/controller/controller.c#L125-L136)
```c
if (state.state == CONTROLLER_STATE_CALIBRATE)
{
    state.is_calibrating = true;
    system_reset_calibration();
    if (ADC_calibrate_offset() &&          // Stage 1: ADC offset
        motor_calibrate_resistance() &&     // Stage 2: Resistance (R)
        motor_calibrate_inductance())       // Stage 3: Inductance (L)
    {
        (void)(sensors_calibrate());       // Stage 4: Encoder
    }
    state.is_calibrating = false;
    controller_set_state(CONTROLLER_STATE_IDLE);
}
```

### Resistance Calibration Timing

**Reference**: [firmware/src/motor/motor.h](firmware/src/motor/motor.h#L41-L44)
```c
#define CAL_R_LEN (2 * PWM_FREQ_HZ)  // 2 seconds @ 20kHz = 40,000 iterations
#define CAL_L_LEN (1 * PWM_FREQ_HZ)  // 1 second @ 20kHz = 20,000 iterations
```

**Why Long Duration?**:
- Averages out noise
- Ensures thermal stability
- Validates measurement consistency

**Rule**: Do not reduce calibration lengths without extensive testing. Shorter calibration = less accurate R/L measurements = unstable FOC control.

### Resistance and Inductance Range Checks

Calibrated values must fall within expected ranges:

**Reference**: [firmware/src/motor/motor.h](firmware/src/motor/motor.h#L25-L39)

**R3.x / R5.x Boards**:
```c
#define MIN_PHASE_RESISTANCE (0.01f)   // 10 mΩ
#define MAX_PHASE_RESISTANCE (1.0f)    // 1 Ω
#define MIN_PHASE_INDUCTANCE (5e-6f)   // 5 μH
#define MAX_PHASE_INDUCTANCE (1e-3f)   // 1 mH
```

**M5.x Boards**:
```c
#define MIN_PHASE_RESISTANCE (0.5f)    // 500 mΩ
#define MAX_PHASE_RESISTANCE (20.0f)   // 20 Ω
#define MIN_PHASE_INDUCTANCE (1e-5f)   // 10 μH
#define MAX_PHASE_INDUCTANCE (1e-2f)   // 10 mH
```

**Why Different Ranges?**:
- **High-current motors**: Low resistance, low inductance
- **Gimbal motors**: High resistance, high inductance

**Errors Raised**:
- `MOTOR_ERRORS_PHASE_RESISTANCE_OUT_OF_RANGE` - R outside valid range
- `MOTOR_ERRORS_PHASE_INDUCTANCE_OUT_OF_RANGE` - L outside valid range

**Action**: If these errors occur, check:
1. Motor is correctly connected (all 3 phases)
2. Motor type matches board (high-current vs gimbal)
3. No shorts or opens in motor windings

### Pole Pair Detection

The firmware automatically detects motor pole pairs by rotating the motor and counting electrical cycles:

**Reference**: [firmware/src/common.h](firmware/src/common.h#L142)
```c
#define MOTOR_MAX_POLE_PAIRS 24
```

**Error Raised**:
- `MOTOR_ERRORS_POLE_PAIRS_OUT_OF_RANGE` - Detected pole pairs <1 or >24
- `MOTOR_ERRORS_POLE_PAIRS_CALCULATION_DID_NOT_CONVERGE` - Inconsistent results

**Action**: Ensure motor is free to rotate and encoder is properly mounted during calibration.

## 🏎️ Velocity Limits

### Hard Velocity Limit

An absolute maximum velocity protects against encoder errors and runaway:

**Reference**: [firmware/src/config.h](firmware/src/config.h#L39)
```c
#define VEL_HARD_LIMIT (600000.0f)  // ticks/s
```

**Calculation**:
- Encoder resolution: 8192 ticks/revolution (common)
- Hard limit: 600,000 ticks/s
- Maximum speed: 600,000 / 8192 ≈ **73 rev/s** ≈ **4,380 RPM**

**Board-Specific Default Limits**:

**R3.x / R5.x Boards** ([firmware/src/controller/controller.c](firmware/src/controller/controller.c#L74)):
```c
.vel_limit = 300000.0f,  // 36.6 rev/s ≈ 2,196 RPM
```

**M5.x Boards** ([firmware/src/controller/controller.c](firmware/src/controller/controller.c#L92)):
```c
.vel_limit = 100000.0f,  // 12.2 rev/s ≈ 732 RPM (gimbal motors)
```

**Warning Flag**: If velocity exceeds limit, `CONTROLLER_WARNINGS_VELOCITY_LIMITED` is set and velocity is clamped.

### Velocity Integrator Deadband

To prevent steady-state error accumulation, the velocity integrator has a deadband:

**Reference**: [firmware/src/controller/controller.c](firmware/src/controller/controller.c#L79)
```c
.vel_integral_deadband = 200.0f,  // ticks/s
```

**Why**: Small steady-state errors (<200 ticks/s ≈ 0.024 rev/s) do not integrate, preventing wind-up.

## ⚙️ Watchdog Protection

The firmware includes a watchdog timer to detect communication loss:

**Reference**: [firmware/src/controller/controller.c](firmware/src/controller/controller.c#L139-L144)
```c
// Check the watchdog and revert to idle if it has timed out
if (Watchdog_triggered())
{
    controller_set_state(CONTROLLER_STATE_IDLE);
    Watchdog_reset();
}
```

**Behavior**:
1. Watchdog must be "fed" regularly via CAN/UART communication
2. If no communication for timeout period → Watchdog triggers
3. Controller automatically enters IDLE state
4. Motor safely stops

**Configuration**: Watchdog timeout is configurable (default: typically 1-2 seconds)

**Purpose**: Prevents runaway if host computer crashes or communication is lost.

## 💾 Non-Volatile Memory (NVM) Safety

### Configuration Persistence

User settings (current limits, gains, etc.) can be saved to flash:

```python
tm.save_config()  # Saves to NVM
tm.erase_config()  # Erases NVM and resets to defaults
```

**Flash Write Limits**:
- **Endurance**: ~10,000 erase/write cycles
- **Retention**: 20+ years at 85°C

**Rule**: Minimize `save_config()` calls to extend flash lifetime. Do not call in loops or high-frequency events.

**Bad Example**:
```python
while True:
    tm.controller.current.Iq_limit += 0.1
    tm.save_config()  # ❌ Will wear out flash quickly!
```

**Good Example**:
```python
tm.controller.current.Iq_limit = 15.0
tm.save_config()  # ✓ Save once after configuration complete
```

## 🧪 Testing Requirements

### Mandatory Testing for Safety-Critical Changes

If you modify any of the following, **comprehensive testing is required**:

**Control Loop Changes**:
- ✓ Test `tm.scheduler.load` on multiple board revisions (R5, M5 minimum)
- ✓ Verify load stays below 3000 cycles under all conditions
- ✓ Test with different motors (high-current and gimbal)
- ✓ Monitor for oscillations, instability, overheating
- ✓ Verify error handling (force errors and confirm IDLE transition)

**Calibration Changes**:
- ✓ Test on 5+ different motors (varying R, L, pole pairs)
- ✓ Verify calibration succeeds consistently (10+ attempts per motor)
- ✓ Check measured R/L values against known specifications
- ✓ Test with noisy power supply (introduce line noise)
- ✓ Verify abnormal voltage detection (short phases, disconnect phase)

**Current Limit Changes**:
- ✓ Gradually increase current and verify trip at 1.5× limit
- ✓ Monitor for hardware damage (smoke, overheating, burnt MOSFETs)
- ✓ Test at different bus voltages (12V, 24V, 48V)
- ✓ Verify warning flags set correctly

**Timing Changes**:
- ✓ Measure actual execution time with oscilloscope (ADC IRQ to PWM update)
- ✓ Test under worst-case conditions (max CPU load)
- ✓ Verify no scheduler warnings (`SCHEDULER_WARNINGS_CONTROL_BLOCK_REENTERED`)

### Test Environments

**Simulation Tests**: No hardware, logic validation only
```bash
cd studio/Python
python -m unittest tests/test_simulation.py
```

**HITL (Hardware-in-the-Loop) Tests**: Requires Tinymovr board and motor
```bash
cd studio/Python
pytest -m hitl_default  # Basic tests
pytest -m eol           # End-of-line comprehensive tests
```

**Stress Tests**: Long-duration reliability testing
- Run motor continuously for 1+ hours
- Monitor temperature, current, voltage
- Check for accumulated errors or warnings

## 🚨 Common Pitfalls

### 1. Blocking in Control Loop

**Problem**: Called `printf()` or `delay()` in control loop

**Symptom**: Control loop overruns, scheduler warning raised, erratic motor behavior

**Solution**: Never block in control loop or ISRs. Use asynchronous logging (RTT) if needed.

### 2. Missing TM_RAMFUNC Annotation

**Problem**: Critical function not marked `TM_RAMFUNC`

**Symptom**: Intermittent timing issues, jitter in motor control, high CPU load

**Solution**: Mark all functions called from control loop with `TM_RAMFUNC`:
```c
TM_RAMFUNC void my_critical_function(void) {
    // This runs from RAM
}
```

### 3. Double-Precision Float

**Problem**: Used `double` instead of `float`

**Symptom**: Extremely high CPU load (>5000 cycles), control loop overruns

**Solution**: ARM Cortex-M4F has single-precision FPU only. Always use `float`:
```c
float value = 3.14f;  // ✓ Correct
double value = 3.14;  // ❌ Will use software emulation (slow!)
```

### 4. Integer Division

**Problem**: Used `/` operator on integers in critical path

**Symptom**: High CPU load, no hardware divider on Cortex-M4

**Solution**: Pre-compute reciprocals or use lookup tables:
```c
// Bad:
int result = value / 123;  // ❌ Software division

// Good:
float result = value * (1.0f / 123.0f);  // ✓ Hardware multiply
```

### 5. Disabling Error Handling

**Problem**: Commented out error checks or IDLE transitions

**Symptom**: Motor runaway, hardware damage, fire hazard

**Solution**: **Never disable error handling**. It's there for safety.

### 6. Reducing Calibration Time

**Problem**: Changed `CAL_R_LEN` to speed up calibration

**Symptom**: Inaccurate R/L measurements, unstable FOC, motor vibration

**Solution**: Keep calibration lengths at default values (2s for R, 1s for L)

### 7. Exceeding Current Limits

**Problem**: Set `I_limit` above hardware capability

**Symptom**: Burnt MOSFETs, damaged PCB traces, destroyed motor

**Solution**: Respect board-specific current ratings:
- R3/R5: Max 30 A peak
- M5: Max 10 A peak

## 📚 Related Documentation

- [ARCHITECTURE.md](ARCHITECTURE.md) - System architecture overview
- [PAC5527_NOTES.md](PAC5527_NOTES.md) - MCU architecture and timing
- [AVLOS_GUIDE.md](AVLOS_GUIDE.md) - Protocol modification guide
- [CLAUDE.md](CLAUDE.md) - Development guidelines for AI agents
- [CONTRIBUTING.md](CONTRIBUTING.md) - Contribution workflow

## 🔐 Safety Checklist for Pull Requests

Before submitting a PR that modifies control code:

- [ ] Read this entire SAFETY.md document
- [ ] Verified no blocking operations in control loop
- [ ] Marked critical functions with TM_RAMFUNC
- [ ] Tested on multiple board revisions (R5, M5)
- [ ] Tested with multiple motors (high-current, gimbal)
- [ ] Verified `tm.scheduler.load` < 3000 cycles
- [ ] Checked error handling and IDLE transitions
- [ ] Ran HITL tests (`pytest -m hitl_default`)
- [ ] Monitored for oscillations, overheating, instability
- [ ] Documented changes in PR description
- [ ] Reviewed changes with maintainer before merging

---

**Document Status**: Living document, updated as firmware safety mechanisms evolve.
**Last Major Update**: Based on firmware v2.3.x with calibration voltage debouncing fix (commit 426ab7e).

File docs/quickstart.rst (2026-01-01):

************************
From Unbox to First Spin
************************

Preparation
###########

Welcome to Tinymovr!

If you are using a Tinymovr Servo Kit/Tinymovr Dev Kit, please ensure you have completed :ref:`connecting-data` and :ref:`connecting-power`.

If you are using a Tinymovr board in your own setup, please go through :ref:`hardware-overview` and :ref:`hardware-setup`.

If using Tinymovr on Windows with a CANtact-compatible CAN Bus adapter, such as CANine, you will need to install an .inf file to enable proper device naming. You can `download the inf file here <https://canable.io/utilities/windows-driver.zip>`_. Extract the archive, right click and select Install.
 
If using CAN bus, you may need to enable at least one termination resistor, either on the CANine adapter, or on one Tinymovr. To enable the termination resistor on CANine, you can take a look at the `CANine connectors diagram <https://canine.readthedocs.io/en/latest/canine.html#hardware-configuration>`_.

Before proceeding to the next steps, ensure your Tinymovr is powered up.

Installing and Launching Studio
###############################

Tinymovr can be installed using pip. Python 3.10 or greater is required.

.. note::
   We recommend installing Tinymovr in a virtual environment. `Here is a quick tutorial on how to setup a virtual environment using Conda <https://conda.io/projects/conda/en/latest/user-guide/getting-started.html#managing-environments>`_.

.. code-block:: console

    pip3 install 'tinymovr[GUI]'
    tinymovr

You should now be looking at the Tinymovr Studio GUI interface.

Installing on Raspberry Pi
##########################

Installation on Raspberry Pi requires a few additional steps.

.. code-block:: console

    sudo apt update
    sudo apt install python3-pip python3-numpy libopenjp2-7 libtiff5
    pip3 install tinymovr

You may also need to append a directory to your PATH variable:

.. code-block:: console

    echo 'export PATH="/home/pi/.local/bin:$PATH"' >> ~/.bashrc
    source ~/.bashrc

Now you should be able to run the Tinymovr CLI:

.. code-block:: console

    tinymovr_cli

Calibrating using the Studio GUI
################################

The Tinymovr Studio GUI offers an overview of the device internals as a tree structure. You can inspect the various values to ensure they are as expected.

The Tinymovr Servo Kit motor and encoder are already calibrated. If you have your own setup, or if you experience problems with prior calibration, you'll need to go through the following brief calibration procedure.

In Tinymovr Studio, navigate to `tm1->controller`. Press the button with the arrow next to the `calibrate` label. Note that after pressing this button, the motor will spin. Ensure the rotor is free of obstructions or loads, and the motor is firmly fixed.

Follow the on-screen prompts. The motor will produce an audible beep and rotate in one direction.
Your Tinymovr is now ready for operation. Navigate to `tm1->motor`. This will reveal identified motor parameters, namely: phase resistance (R), phase inductance (L) and number of pole pairs.

Testing Position Control using the Studio GUI
#############################################

Navigate back to `tm1->controller`. Press the button with the arrow next to the `position_mode` label. Note that after pressing the button, the motor will hold position and may spin. The motor should now be actively holding it's position. Try moving it by hand and you should feel resistance.

To command a new position, navigate to `tm1->controller->position`, and double-click on the value next to the `setpoint` label. This value is expressed in ticks, a unit that denotes 1/8192 of the circle. Type in a new position followed by Enter. The motor should jump to the commanded position.

Connecting More Than 1 Tinymovrs
#################################

Multiple Tinymovr devices can coexist on the same CAN bus network, enabling multi-axis control for applications like robotic arms, gantries, and other coordinated motion systems. The key requirement is that each device must have a unique CAN bus ID. By default, all Tinymovr boards ship with ID 1.

Physical Connections
********************

When connecting multiple Tinymovrs, you'll need to wire them in a daisy-chain topology on the CAN bus:

1. Connect CAN High and CAN Low between devices (CAN High to CAN High, CAN Low to CAN Low)
2. Ensure proper termination resistors are enabled at both ends of the CAN bus. You can use the termination on your CANine adapter (see :ref:`connecting-data`) for one end, and enable the onboard termination resistor on the last Tinymovr in the chain for the other end.
3. Each Tinymovr needs its own power connection

Assigning Unique IDs
********************

To assign different IDs to each board, follow this process:

1. Connect a single Tinymovr to the bus and launch Tinymovr Studio
2. The board will appear as `tm1` with the default ID of 1
3. In the Studio GUI, navigate to the device's CAN settings and change the ID to your desired value (IDs can range from 1 to 1024)
4. Save the configuration using the Save Config button in the GUI
5. Power down the board
6. Repeat the process for each additional Tinymovr, assigning each one a unique ID

Once configured, all devices will automatically appear in Tinymovr Studio with their respective IDs (tm1, tm2, tm3, etc.). You can then control them individually or coordinate their motion for synchronized multi-axis operation.

For detailed step-by-step instructions with screenshots, please see :ref:`multiple-instances`.

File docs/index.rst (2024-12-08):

.. Tinymovr documentation master file, created by
   sphinx-quickstart on Wed Jul 15 14:48:40 2020.
   You can adapt this file completely to your liking, but it should at least
   contain the root `toctree` directive.

Welcome to Tinymovr documentation!
========================================

.. note::
   This is the documentation for the latest stable version of the Tinymovr Firmware and Studio app. For the legacy 0.x.x documentation, check out the [legacy docs](https://tinymovr.readthedocs.io/en/attic-legacy/).

.. note::
   In all examples, the first intance of the found motor controller is used, namely `tm1`. If working with subsequent instances, please replace with the correct index, e.g. instead of `tm1` use `tm2`, `tm3` etc.

.. toctree::
   :maxdepth: 2
   :caption: Contents:

   quickstart
   
   hardware/overview
   hardware/guide
   
   studio/installation
   studio/usage
   
   protocol/integrating
   interfaces/interfaces
   
   sensors/sensors
   features/features
   upgrade/upgrade
   hardware/gimbal

   control/tuning
   control/theory
   troubleshooting
   develop/guide
   
   hardware/errata

   protocol/reference

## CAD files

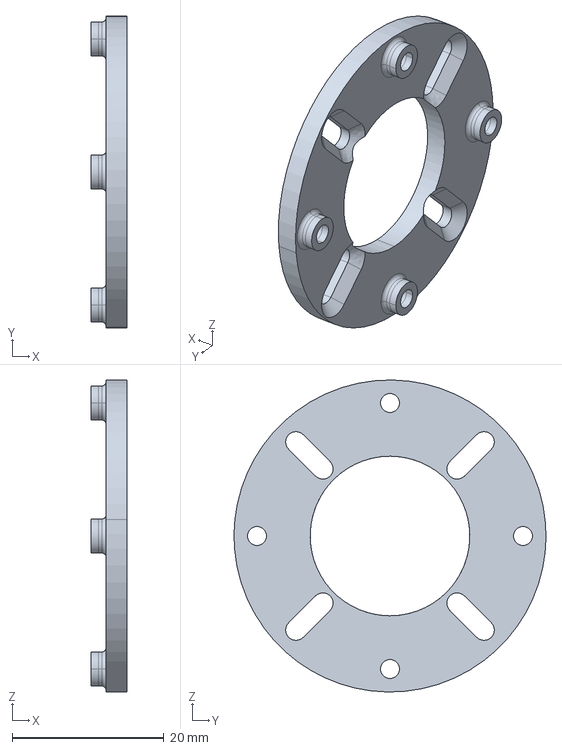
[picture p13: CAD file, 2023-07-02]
hardware/M5/gimbal_bracket.stp
4.80 x 41.1 x 41.1 mm

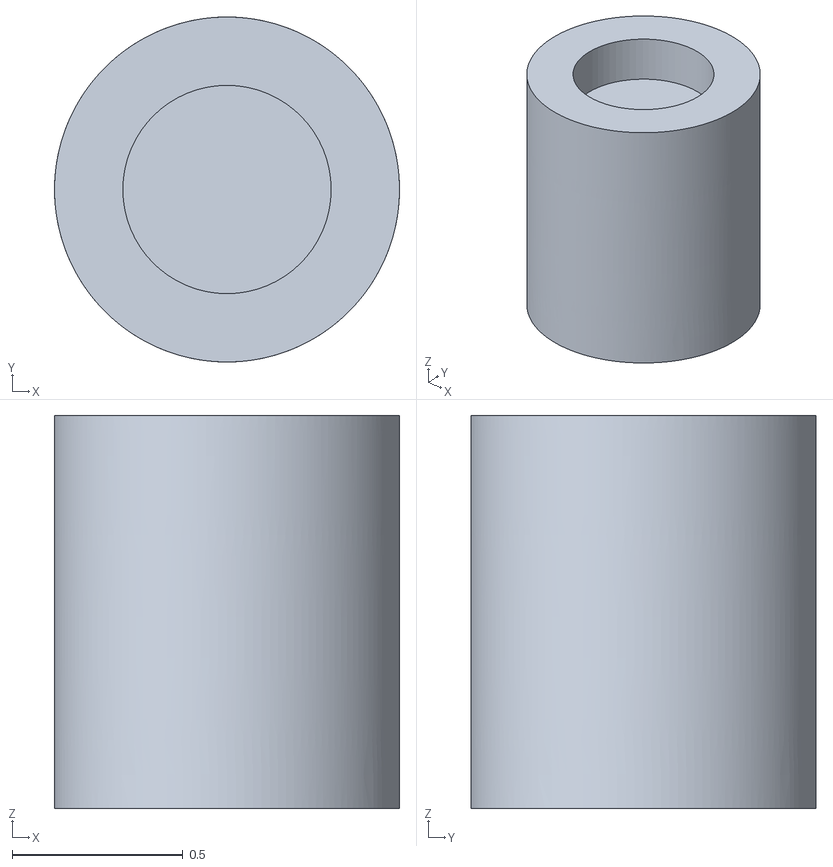
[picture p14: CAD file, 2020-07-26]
hardware/misc/alpha/DevKit_alpha/DevKit_alpha_magnet.stl
1.01 x 1.01 x 1.15

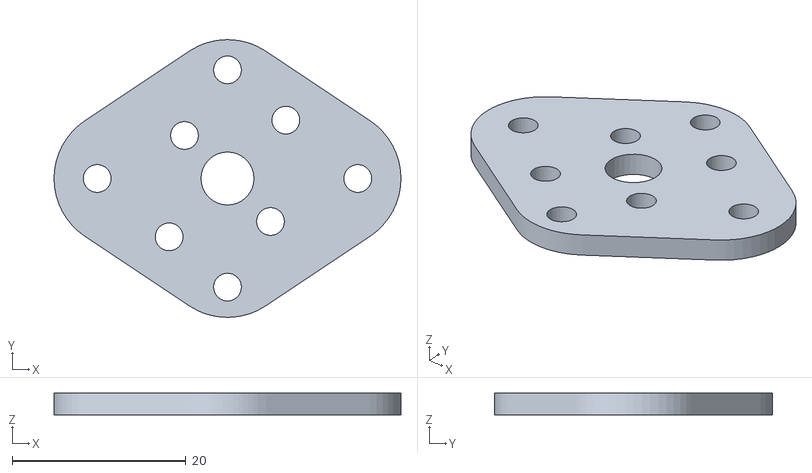
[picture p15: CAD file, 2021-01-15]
hardware/misc/magnet_jig.stl
39.9 x 32.0 x 2.50

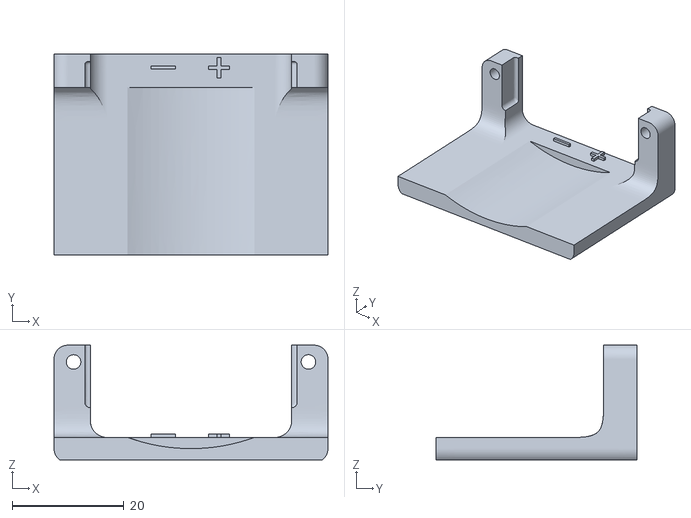
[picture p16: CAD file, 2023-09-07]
hardware/ServoKit/tinymovr_servokit_r5_type_A_part2.stl
49.0 x 36.0 x 20.5

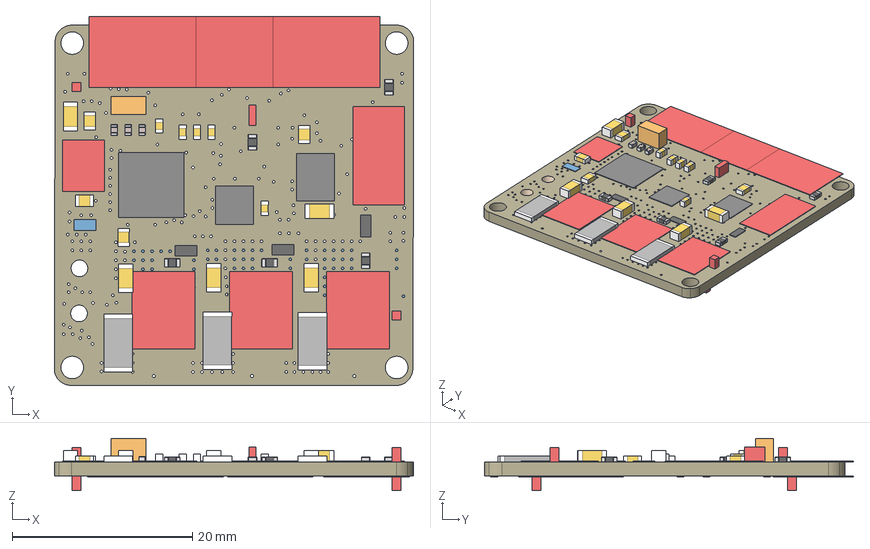
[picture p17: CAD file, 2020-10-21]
hardware/tinymovr-R3.3/TinymovrR3.3.step
39.9 x 41.0 x 5.79 mm
Board
FDMD8530 x 3
PMR100HZPFV2L00 x 3
SHORTT5 x 3
EXB2HV101J
3300pF x 3
4.7uF x 5
MA702GQ-P
PAC5527QM
ASPI-4030S-330M-T
GCM188R71H104KA57J
1uF 50V x 4
2k x 5
DF13A-4P-1.25H(21) x 4
1N4148X-TP x 3
218-2LPSTRF
HHXJ350ARA181MHA0G x 3
C3216X7R1H106K160AC x 5
UJA1162ATK_0Z
SML0603
FIDUCIAL1X2 x 4
TEST-POINT3 x 14

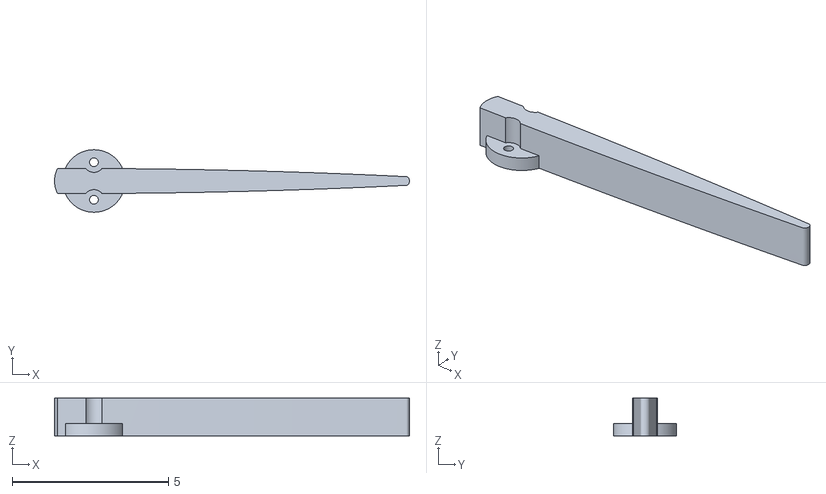
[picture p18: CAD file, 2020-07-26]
hardware/misc/alpha/DevKit_alpha/DevKit_alpha_pointer.stl
11.4 x 2.00 x 1.20

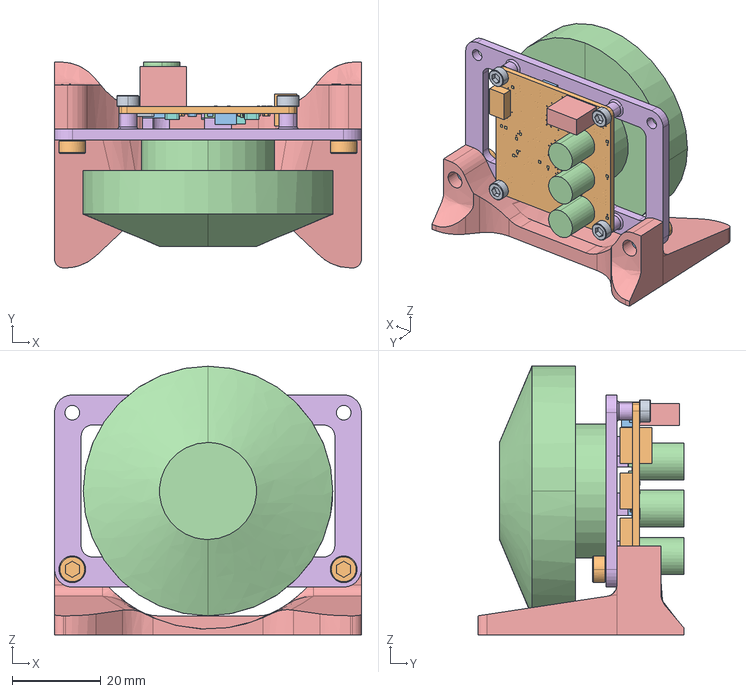
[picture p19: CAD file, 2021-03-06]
hardware/ServoKit/tinymovr_servokit_r2.stp
69.0 x 46.3 x 60.4 mm

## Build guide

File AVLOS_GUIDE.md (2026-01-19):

# Avlos Framework Guide

## What is Avlos?

**Avlos** is a schema-driven code generation framework that automatically creates communication protocol implementations for embedded systems. It generates both firmware (C code) and client library (Python) code from a single YAML specification, ensuring perfect synchronization between device and host.

**Key Benefits**:
- **Single Source of Truth**: One YAML file defines the entire API surface
- **Zero Boilerplate**: No manual protocol wrapper coding required
- **Type Safety**: Automatic serialization/deserialization with type checking
- **Version Control**: Protocol hash ensures firmware-client compatibility
- **Self-Documenting**: API documentation generated from YAML summaries

**Avlos Repository**: https://github.com/tinymovr/avlos

## How Tinymovr Uses Avlos

Tinymovr's entire CAN bus protocol (97 endpoints) is defined in YAML and automatically generated into:
1. **Firmware**: C functions for handling CAN messages ([firmware/src/can/can_endpoints.c](firmware/src/can/can_endpoints.c))
2. **Python Client**: Dynamic Python objects with attribute access ([studio/Python/tinymovr/](studio/Python/tinymovr/))
3. **Documentation**: RST reference documentation ([docs/protocol/reference.rst](docs/protocol/reference.rst))

**Current Protocol Version**: Hash `641680925` (v2.3.x)

## YAML Specification Structure

### Basic Anatomy

Avlos specs are hierarchical trees of `remote_attributes`. Each attribute can represent:
- **Readable value** (with `getter_name`)
- **Writable value** (with `setter_name`)
- **Callable function** (with `caller_name`)
- **Nested namespace** (with child `remote_attributes`)

**Reference**: [studio/Python/tinymovr/specs/tinymovr_2_3_x.yaml](studio/Python/tinymovr/specs/tinymovr_2_3_x.yaml)

### Example: Simple Read-Only Attribute

```yaml
name: tm
remote_attributes:
  - name: Vbus
    dtype: float
    unit: volt
    meta: {dynamic: True}
    getter_name: system_get_Vbus
    summary: The measured bus voltage.
```

**Generated Firmware** ([firmware/src/can/can_endpoints.h](firmware/src/can/can_endpoints.h)):
```c
// Endpoint ID: 4
uint8_t avlos_Vbus(uint8_t * buffer, uint8_t * buffer_len, Avlos_Command cmd);
```

**Generated Python**:
```python
voltage = tm.Vbus  # Automatically calls avlos_Vbus endpoint
```

### Example: Read-Write Attribute

```yaml
- name: position
  remote_attributes:
    - name: setpoint
      dtype: float
      unit: tick
      getter_name: controller_get_pos_setpoint_user_frame
      setter_name: controller_set_pos_setpoint_user_frame
      summary: The position setpoint in user frame.
```

**Generated Python**:
```python
tm.controller.position.setpoint = 5000  # Write via setter
current_setpoint = tm.controller.position.setpoint  # Read via getter
```

### Example: Callable Function

```yaml
- name: calibrate
  summary: Initiate calibration sequence.
  caller_name: controller_calibrate
  dtype: void
  arguments: []
```

**Generated Python**:
```python
tm.controller.calibrate()  # Calls controller_calibrate() on device
```

### Example: Enum/Options

```yaml
- name: state
  options: [IDLE, CALIBRATE, CL_CONTROL]
  getter_name: controller_get_state
  setter_name: controller_set_state
  summary: The current controller state.
```

**Generated Firmware** ([firmware/src/tm_enums.h](firmware/src/tm_enums.h)):
```c
typedef enum
{
    CONTROLLER_STATE_IDLE = 0,
    CONTROLLER_STATE_CALIBRATE = 1,
    CONTROLLER_STATE_CL_CONTROL = 2
} controller_state_options;
```

**Generated Python**:
```python
tm.controller.state = 2  # Set to CL_CONTROL
if tm.controller.state == 0:  # Check if IDLE
    print("Device is idle")
```

### Example: Flags (Bitmasks)

```yaml
- name: errors
  flags: [UNDERVOLTAGE]
  meta: {dynamic: True}
  getter_name: system_get_errors
  summary: Any system errors, as a bitmask
```

**Generated Firmware**:
```c
typedef enum
{
    ERRORS_NONE = 0,
    ERRORS_UNDERVOLTAGE = (1 << 0)
} errors_flags;
```

**Usage**:
```python
if tm.errors & (1 << 0):  # Check UNDERVOLTAGE bit
    print("Undervoltage detected!")
```

## Attribute Properties

### Required Properties

- **`name`**: Identifier for the attribute (used in Python API and C function names)
- **`summary`**: Brief description (appears in documentation and generated comments)

### Data Type Properties

- **`dtype`**: Data type - `float`, `uint32`, `int32`, `uint16`, `int16`, `uint8`, `int8`, `bool`, `string`, `void`
- **`unit`**: Physical unit - `tick`, `ampere`, `volt`, `degC`, `ohm`, `henry`, `watt`, etc.
- **`options`**: List of enum values (mutually exclusive with `flags`)
- **`flags`**: List of bitmask flag names (mutually exclusive with `options`)

### Access Properties

- **`getter_name`**: C function name for reading the value
- **`setter_name`**: C function name for writing the value
- **`caller_name`**: C function name for calling (void functions)
- **`arguments`**: List of argument definitions for callable functions

### Metadata

- **`meta`**: Dictionary of optional metadata
  - `dynamic: True` - Value changes frequently (read every time)
  - `reload_data: True` - Causes device reset/reload after call

### Nested Attributes

```yaml
- name: controller
  remote_attributes:
    - name: position
      remote_attributes:
        - name: setpoint
          dtype: float
          ...
```

**Generates Nested Access**:
```python
tm.controller.position.setpoint = 1000
```

## Code Generation Configuration

The code generation process is configured in [avlos_config.yaml](avlos_config.yaml):

```yaml
generators:
  generator_c:
    enabled: true
    paths:
      output_enums: ./firmware/src/tm_enums.h
      output_header: ./firmware/src/can/can_endpoints.h
      output_impl: ./firmware/src/can/can_endpoints.c
    header_includes:
    - src/common.h
    - src/tm_enums.h
    impl_includes:
    - <string.h>
    - src/adc/adc.h
    - src/system/system.h
    - src/sensor/sensors.h
    - src/observer/observer.h
    - src/motor/motor.h
    - src/scheduler/scheduler.h
    - src/controller/controller.h
    - src/nvm/nvm.h
    - src/watchdog/watchdog.h
    - src/can/can_endpoints.h
  generator_rst:
    enabled: true
    paths:
      output_file: ./docs/protocol/reference.rst
```

## Complete Workflow: Adding a New Endpoint

### Step 1: Edit YAML Specification

Let's add a motor temperature estimation endpoint:

**File**: [studio/Python/tinymovr/specs/tinymovr_2_3_x.yaml](studio/Python/tinymovr/specs/tinymovr_2_3_x.yaml)

Find the `motor` section and add:

```yaml
- name: motor
  remote_attributes:
    # ... existing attributes ...
    - name: temperature
      dtype: float
      unit: degC
      meta: {dynamic: True}
      getter_name: motor_get_temperature
      summary: Estimated motor temperature from resistance change.
```

### Step 2: Run Code Generator

```bash
cd studio/Python/tinymovr/specs
avlos from file <spec_file>.yaml
```

Replace `<spec_file>` with the appropriate protocol version spec file (e.g., `tinymovr_2_3_x`, `tinymovr_2_4_x`, etc.). Use the spec file that matches the firmware version you're working with.

**Output**:
```
Generating C code...
  Written: firmware/src/tm_enums.h
  Written: firmware/src/can/can_endpoints.h
  Written: firmware/src/can/can_endpoints.c
Generating RST documentation...
  Written: docs/protocol/reference.rst
Protocol hash: 641680925 -> 789456123 (CHANGED!)
```

**Important**: The protocol hash **will change** with any YAML modification. This breaks compatibility with existing firmware.

### Step 3: Implement C Function

Create the getter function in [firmware/src/motor/motor.c](firmware/src/motor/motor.c):

```c
float motor_get_temperature(void)
{
    // Estimate temperature from resistance change
    // T = T_cal + (R - R_cal) / (R_cal * alpha)
    // where alpha = temperature coefficient of copper (0.00393 / °C)

    MotorConfig *config = motor_get_config();
    float R_cal = config->phase_resistance;  // Resistance at calibration
    float T_cal = 25.0f;  // Assumed calibration temperature (°C)
    float alpha = 0.00393f;  // Copper temp coefficient

    // Measure current resistance (simplified)
    float R_current = R_cal;  // TODO: Implement actual measurement

    float delta_T = (R_current - R_cal) / (R_cal * alpha);
    return T_cal + delta_T;
}
```

Add declaration to [firmware/src/motor/motor.h](firmware/src/motor/motor.h):

```c
float motor_get_temperature(void);
```

### Step 4: Build Firmware

```bash
cd firmware
make release REV=R52
```

**Verify**:
- No compilation errors
- Binary size hasn't exceeded flash capacity
- New endpoint included in endpoint array (97 -> 98 endpoints)

### Step 5: Flash Firmware

```bash
# Using J-Link (example)
JLinkExe -device PAC5527 -if SWD -speed 4000
> loadbin build/tinymovr_fw.bin 0x00000000
> r
> g
> exit
```

### Step 6: Test Python Client

The Python client automatically generates the new attribute from the YAML spec:

```python
from tinymovr import init_router, create_device
from tinymovr.config import get_bus_config
import can

# Initialize CAN bus
params = get_bus_config(["canine", "slcan_disco"], bitrate=1000000)
init_router(can.Bus, params)

# Create device
tm = create_device(node_id=1)

# Check protocol hash matches
print(f"Protocol hash: {tm.protocol_hash}")  # Should be 789456123

# Read new endpoint
temp = tm.motor.temperature
print(f"Motor temperature: {temp:.1f} °C")
```

### Step 7: Write Tests

Add test to [studio/Python/tests/test_board.py](studio/Python/tests/test_board.py):

```python
@pytest.mark.hitl_default
def test_motor_temperature(self):
    """Test motor temperature estimation"""
    self.try_calibrate()

    # Read temperature
    temp = self.tm.motor.temperature

    # Sanity check: temperature should be reasonable
    self.assertGreater(temp, 0.0)   # Above absolute zero
    self.assertLess(temp, 150.0)    # Below typical motor max
```

Run test:

```bash
cd studio/Python
pytest -m hitl_default tests/test_board.py::TestTinymovr::test_motor_temperature
```

## Protocol Hash System

### What is the Protocol Hash?

The protocol hash is a **32-bit checksum** computed from the entire YAML spec structure. It ensures firmware and client are using compatible protocol definitions.

**Reference**: [firmware/src/can/can_endpoints.h](firmware/src/can/can_endpoints.h#L13)
```c
static const uint32_t avlos_proto_hash = 641680925;
```

### Hash Verification on Connection

When the Python client connects to a device:

1. Read device's `protocol_hash` endpoint (endpoint ID 0)
2. Compare to hash computed from local YAML spec
3. If mismatch → Raise `IncompatibleSpecVersionError`

**Reference**: [studio/Python/tinymovr/config/config.py](studio/Python/tinymovr/config/config.py#L46-L64)

```python
def get_device_spec(hash, logger=None):
    try:
        return specs["hash_uint32"][hash]
    except KeyError:
        # Try hash aliases for backward compatibility
        for hash_alias in hash_aliases.get(hash, []):
            try:
                return specs["hash_uint32"][hash_alias]
            except KeyError:
                pass
    return None  # No compatible spec found
```

### When Does the Hash Change?

The hash changes when **any** of the following are modified in the YAML:
- Add/remove/rename an attribute
- Change data type (`dtype`)
- Change unit
- Modify options/flags
- Change nesting structure
- Change order of attributes (endpoint IDs shift)

### Breaking vs. Non-Breaking Changes

**Breaking Changes** (new hash required):
- Adding new endpoints → Endpoint IDs shift → Hash changes
- Changing data types → Serialization incompatible → Hash changes
- Removing endpoints → Missing functionality → Hash changes

**Non-Breaking Changes** (can use hash aliases):
- Fixing typos in `summary` → Hash changes but protocol compatible
- Changing metadata (`meta`) → Hash changes but protocol compatible

**Hash Aliases** ([studio/Python/tinymovr/config/config.py](studio/Python/tinymovr/config/config.py#L43)):
```python
# Allow old clients to work with new firmware if only cosmetic changes
hash_aliases = {3526126264: [4118115615]}
```

## Multi-Version Support

### Version-Specific YAML Files

Tinymovr maintains multiple YAML specs for different firmware versions:

```
studio/Python/tinymovr/specs/
├── tinymovr_1_3_x.yaml  # Legacy v1.3.x
├── tinymovr_1_4_x.yaml  # Legacy v1.4.x
├── tinymovr_2_0_x.yaml  # v2.0.x
├── tinymovr_2_1_x.yaml  # v2.1.x
├── tinymovr_2_2_x.yaml  # v2.2.x
└── tinymovr_2_3_x.yaml  # Current v2.3.x (hash: 641680925)
```

### Automatic Spec Selection

The Python client automatically selects the correct spec based on device hash:

```python
# Device discovery reads protocol_hash from device
device_hash = 641680925  # Read from device

# Load matching spec
spec = get_device_spec(device_hash)
if spec is None:
    raise IncompatibleSpecVersionError(device_hash)

# Deserialize spec into Python object tree
tm = deserialize(spec)
```

### Maintaining Backward Compatibility

**Best Practices**:
1. **Never remove endpoints** - Mark as deprecated instead
2. **Append new endpoints** - Add to end to avoid shifting IDs
3. **Create new version** - Copy YAML, modify, update hash
4. **Test with old clients** - Ensure graceful degradation

**Example: Deprecation Pattern**:
```yaml
- name: old_parameter
  dtype: float
  getter_name: get_old_parameter
  summary: "[DEPRECATED] Use new_parameter instead."
```

## Breaking Changes and Protocol Versioning

### When to Create a New Protocol Version

**Always create a new protocol version** (e.g., 2.3.x → 2.4.x) when making breaking changes:

1. **API Structure Changes**
   - Moving endpoints to new namespaces
   - Renaming endpoints
   - Changing endpoint hierarchy

2. **Data Type Changes**
   - Changing `dtype` of existing endpoint
   - Changing units
   - Changing enum values or flags

3. **Removing Endpoints**
   - Deleting functionality (even if deprecated)

**Never** create new versions for:
- Adding new endpoints (append to end of spec)
- Fixing typos in documentation (`summary` fields)
- Adding metadata (`meta` fields)
- Internal implementation changes

### How to Create a New Protocol Version

1. **Copy the previous version file**:
   ```bash
   cp studio/Python/tinymovr/specs/tinymovr_2_3_x.yaml \
      studio/Python/tinymovr/specs/tinymovr_2_4_x.yaml
   ```

2. **Make breaking changes** in the new file

3. **Generate code** for both versions:
   ```bash
   avlos from file <spec_file>.yaml
   ```

4. **Update firmware** to use new generated code

5. **Test with Python client** - it will automatically detect version via protocol hash

6. **Keep old version file** for backward compatibility with older firmware

### Example: Adding Monitoring Endpoints Under New Namespace

When adding new monitoring/debug endpoints, group them under a descriptive namespace while keeping user-facing operations at the top level for backward compatibility.

**Before** (v2.3.x):
```yaml
name: tm
remote_attributes:
  - name: save_config
    caller_name: nvm_save_config
    dtype: void
  - name: erase_config
    caller_name: nvm_erase_and_reset
    dtype: void
```

**After** (v2.4.x) - Adding wear leveling monitoring:
```yaml
name: tm
remote_attributes:
  # User operations stay at top level (no breaking changes)
  - name: save_config
    caller_name: nvm_save_config
    dtype: void
  - name: erase_config
    caller_name: nvm_erase_and_reset
    dtype: void
  # New monitoring endpoints under nvm namespace
  - name: nvm
    remote_attributes:
      - name: num_slots
        getter_name: nvm_wl_get_num_slots
        dtype: uint8
      - name: current_slot
        getter_name: nvm_wl_get_current_slot
        dtype: uint8
      - name: write_count
        getter_name: nvm_wl_get_write_count
        dtype: uint32
```

**Impact**:
- User operations unchanged: `tm.save_config()`, `tm.erase_config()` (backward compatible)
- New monitoring API: `tm.nvm.num_slots`, `tm.nvm.write_count`, etc.
- Protocol hash changes (2.3.x clients won't see new endpoints, but existing code works)
- Tests can detect protocol version via `hasattr(tm, 'nvm')` for optional features

### Version Numbering Convention

- **Major version** (e.g., 1.x → 2.x): Major firmware rewrite, architecture change
- **Minor version** (e.g., 2.3.x → 2.4.x): Breaking protocol changes, API reorganization
- **Patch version** (within x.y.x): Usually not reflected in spec filename, used for firmware-only changes

## Generated Code Structure

### Firmware (C)

#### Enumerations ([firmware/src/tm_enums.h](firmware/src/tm_enums.h))

```c
// Auto-generated from YAML
typedef enum
{
    CONTROLLER_STATE_IDLE = 0,
    CONTROLLER_STATE_CALIBRATE = 1,
    CONTROLLER_STATE_CL_CONTROL = 2
} controller_state_options;

typedef enum
{
    MOTOR_ERRORS_NONE = 0,
    MOTOR_ERRORS_PHASE_RESISTANCE_OUT_OF_RANGE = (1 << 0),
    MOTOR_ERRORS_PHASE_INDUCTANCE_OUT_OF_RANGE = (1 << 1),
    // ... more error flags
} motor_errors_flags;
```

#### Endpoint Array ([firmware/src/can/can_endpoints.h](firmware/src/can/can_endpoints.h#L14))

```c
// Array of 97 function pointers, indexed by endpoint ID
extern uint8_t (*avlos_endpoints[97])(uint8_t * buffer,
                                       uint8_t * buffer_len,
                                       Avlos_Command cmd);
```

#### Endpoint Functions ([firmware/src/can/can_endpoints.c](firmware/src/can/can_endpoints.c))

```c
uint8_t avlos_Vbus(uint8_t * buffer, uint8_t * buffer_len, Avlos_Command cmd)
{
    if (cmd == AVLOS_CMD_READ)
    {
        float value = system_get_Vbus();  // Call implementation
        serialize_float(value, buffer);   // Pack into CAN frame
        *buffer_len = sizeof(float);
        return AVLOS_RET_READ;
    }
    return AVLOS_RET_NOACTION;
}
```

### Python Client

#### Dynamic Object Tree

The Python client creates a nested object structure at runtime:

```python
from avlos.deserializer import deserialize

# Load YAML spec
spec = yaml.safe_load(open("tinymovr_2_3_x.yaml"))

# Deserialize into Python objects
tm = deserialize(spec)

# Object hierarchy mirrors YAML structure
tm.Vbus                              # Float attribute
tm.controller.state                   # Enum attribute
tm.controller.position.setpoint       # Nested float attribute
tm.controller.calibrate()            # Callable method
```

#### Unit-Aware Quantities (Pint Integration)

Attributes with `unit` in YAML return Pint quantities:

```python
from pint import UnitRegistry
ureg = UnitRegistry()

# Reading returns unit-aware quantity
voltage = tm.Vbus  # Returns: 24.0 <Unit('volt')>

# Writing accepts units
tm.controller.current.Iq_setpoint = 2.5 * ureg.ampere

# Or plain floats (assumes base unit)
tm.controller.current.Iq_setpoint = 2.5  # Interpreted as amperes
```

## Testing Protocol Changes

### Hardware-in-the-Loop (HITL) Tests

All protocol changes **must** be validated with HITL tests:

```bash
cd studio/Python

# Run full test suite (requires hardware)
pytest -m hitl_default

# Run specific test
pytest -m hitl_default tests/test_board.py::TestTinymovr::test_position_control

# Run end-of-line comprehensive tests
pytest -m eol
```

### Test Structure

HITL tests use [studio/Python/tests/tm_test_case.py](studio/Python/tests/tm_test_case.py) base class:

```python
import pytest
from tests.tm_test_case import TMTestCase

class TestNewEndpoint(TMTestCase):
    @pytest.mark.hitl_default
    def test_new_endpoint_read(self):
        """Test reading new endpoint"""
        self.try_calibrate()  # Calibrate if needed

        value = self.tm.new_endpoint
        self.assertIsNotNone(value)

    @pytest.mark.hitl_default
    def test_new_endpoint_write(self):
        """Test writing new endpoint"""
        self.try_calibrate()

        self.tm.new_endpoint = 123.45
        readback = self.tm.new_endpoint

        self.assertAlmostEqual(readback, 123.45, delta=0.01)
```

### Simulation Tests (No Hardware)

For logic that doesn't require hardware:

```python
# tests/test_simulation.py
import unittest

class TestProtocolHash(unittest.TestCase):
    def test_hash_consistency(self):
        """Verify protocol hash computation is deterministic"""
        from tinymovr.config import specs

        # Load spec twice
        spec1 = specs["hash_uint32"][641680925]
        spec2 = specs["hash_uint32"][641680925]

        # Hashes should match
        self.assertEqual(spec1, spec2)
```

## Common Pitfalls

### 1. Forgetting to Regenerate Code

**Problem**: Modified YAML but didn't run `avlos.generate`

**Symptom**: Python client has new attribute, firmware doesn't recognize it

**Solution**: Always run code generation after YAML changes:
```bash
avlos from file <spec_file>.yaml
```

### 2. Editing Generated Files Directly

**Problem**: Modified `can_endpoints.c` or `tm_enums.h` manually

**Symptom**: Changes lost on next code generation

**Solution**: Never edit generated files. They have warnings at the top:
```c
/*
* This file was automatically generated using Avlos.
* Any changes to this file will be overwritten when
* content is regenerated.
*/
```

### 3. C Function Doesn't Exist

**Problem**: Added endpoint with `getter_name` but function not implemented

**Symptom**: Linker error: `undefined reference to 'motor_get_temperature'`

**Solution**: Implement the C function before building firmware

### 4. Type Mismatch

**Problem**: YAML says `dtype: uint32` but C function returns `float`

**Symptom**: Garbage data, incorrect values, or crashes

**Solution**: Ensure C function signature matches YAML dtype:
```yaml
dtype: uint32   → uint32_t function_name(void)
dtype: float    → float function_name(void)
dtype: bool     → bool function_name(void)
```

### 5. Protocol Hash Mismatch

**Problem**: Firmware and Python client have different protocol hashes

**Symptom**: `IncompatibleSpecVersionError` on device connection

**Solution**:
- Flash updated firmware with new hash
- Or revert YAML changes to match firmware
- Or add hash alias for backward compatibility

## Advanced Topics

### Custom Data Types

Avlos supports structures via nested attributes:

```yaml
- name: pid_gains
  remote_attributes:
    - name: kp
      dtype: float
      getter_name: controller_get_kp
      setter_name: controller_set_kp
    - name: ki
      dtype: float
      getter_name: controller_get_ki
      setter_name: controller_set_ki
```

**Access**:
```python
tm.controller.pid_gains.kp = 0.5
tm.controller.pid_gains.ki = 0.01
```

### Function Arguments

Callables can accept arguments:

```yaml
- name: set_limits
  caller_name: controller_set_limits
  dtype: void
  arguments:
    - name: vel_limit
      dtype: float
      unit: tick/s
    - name: current_limit
      dtype: float
      unit: ampere
```

**Generated C**:
```c
void controller_set_limits(float vel_limit, float current_limit);
```

**Python Call**:
```python
tm.controller.set_limits(100000, 5.0)
```

### Dynamic vs. Static Attributes

Attributes marked `meta: {dynamic: True}` are **read every time**:

```yaml
- name: Vbus
  dtype: float
  meta: {dynamic: True}  # Read from device on every access
  getter_name: system_get_Vbus
```

Static attributes (no `dynamic` flag) are **cached**:

```yaml
- name: hw_revision
  dtype: uint32
  getter_name: system_get_hw_revision  # Read once, cached
```

## References

### Avlos Framework
- **Repository**: https://github.com/tinymovr/avlos
- **Documentation**: https://github.com/tinymovr/avlos/blob/main/README.md

### Tinymovr Files
- [avlos_config.yaml](avlos_config.yaml) - Code generation configuration
- [studio/Python/tinymovr/specs/](studio/Python/tinymovr/specs/) - YAML specifications
- [firmware/src/can/can_endpoints.h](firmware/src/can/can_endpoints.h) - Generated C header
- [firmware/src/can/can_endpoints.c](firmware/src/can/can_endpoints.c) - Generated C implementation
- [firmware/src/tm_enums.h](firmware/src/tm_enums.h) - Generated enumerations
- [studio/Python/tinymovr/config/config.py](studio/Python/tinymovr/config/config.py) - Spec loading
- [docs/protocol/reference.rst](docs/protocol/reference.rst) - Generated documentation

### Related Documentation
- [ARCHITECTURE.md](ARCHITECTURE.md) - System architecture overview
- [CLAUDE.md](CLAUDE.md) - Development guidelines for AI agents
- [SAFETY.md](SAFETY.md) - Safety-critical constraints

---

**Document Status**: Living document, updated as Avlos framework evolves.
**Current Version**: Based on Avlos v0.6.6+ and Tinymovr firmware v2.3.x.

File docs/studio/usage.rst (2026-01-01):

************
Studio Usage
************

.. |cli| raw:: html

   <span style="padding:3px 10px;margin: 10px auto; background:#85dff1; border-radius: 12px; font-family: sans-serif; font-size: 14px;">CLI</span>

.. |gui| raw:: html

   <span style="padding:3px 10px;margin: 10px auto; background:#85f1df; border-radius: 12px; font-family: sans-serif; font-size: 14px;">GUI</span>

Tinymovr Studio is a cross-platform GUI application, CLI application, and Python library that offers easy access to all of Tinymovr's functionality.

This documentation page includes examples both for the |gui| as well as the |cli| apps. 

Launching Studio
################

|gui|

.. code-block:: console

    tinymovr

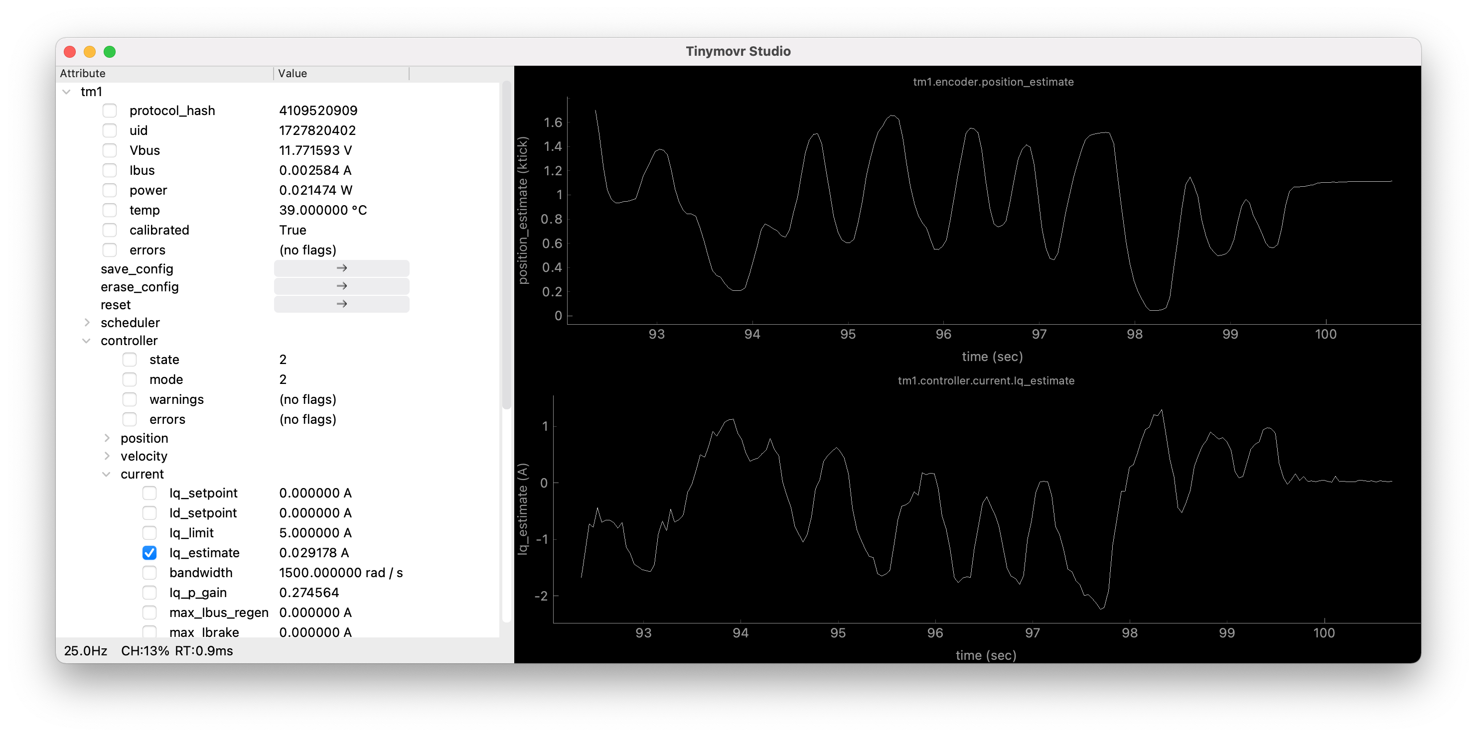
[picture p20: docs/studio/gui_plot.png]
Tinymovr Studio GUI with plot


|cli|

.. code-block:: console

    tinymovr_cli

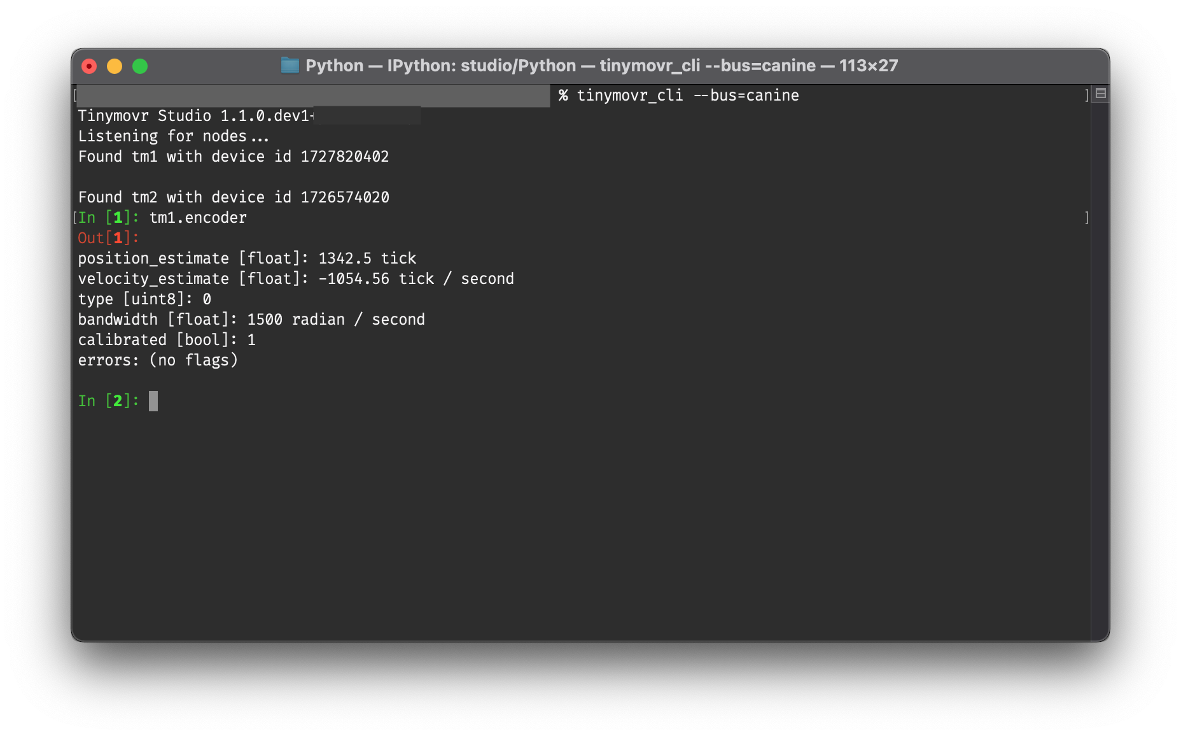
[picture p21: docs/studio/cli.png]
Tinymovr Studio CLI


Alternative Adapters/Firmwares
##############################

By default Tinymovr Studio searches for either slcan-compatible CAN bus adapters or adapters using the `CANine firmware <https://github.com/tinymovr/CANine>`_ [1]_. To specify an alternative device, use the `--bus` command line argument. 

For instance, to work with SocketCAN-compatible adapters in linux, launch Tinymovr Studio as follows:

|gui|

.. code-block:: console

    tinymovr --bus=socketcan

|cli|

.. code-block:: console

    tinymovr_cli --bus=socketcan

.. [1] Note that you need to have completed `setting up CANine <https://canine.readthedocs.io/en/latest/canine.html#canine-firmware>`_ before working with CANine.

Compatibility
#############

Tinymovr Studio includes by default a checksum comparison to determine protocol compatibility between firmware and studio version. This is performed each time a node is discovered, and prior to initializing the tinymovr object. If you see a compatibility-related message, please upgrade to the latest studio and firmware versions. 

Custom Device Specs
###################

You can specify a custom device spec (YAML file) as a command line argument:

|gui|

.. code-block:: console

    tinymovr --spec=/path/to/myspec.yaml

|cli|

.. code-block:: console

    tinymovr_cli --spec=/path/to/myspec.yaml

This is useful, for instance, if you have altered the default Tinymovr spec files. Using this parameter with a project developed using `Avlos <https://github.com/tinymovr/avlos>`_, you can even use Tinymovr Studio to control your own custom devices!

Issuing Commands in CLI
#######################

|cli|

You can read/write variables and issue commands using the respective Tinymovr handle, e.g.:

.. code-block:: python

    tm1.encoder

or

.. code-block:: python

    tm1.controller.pos_setpoint = 10000

Replace "tm1" with the correct device ID if necessary. Full tab completion is available.

.. _multiple-instances:

Multiple Instances
##################

In order for multiple Tinymovr instances to coexist in the same CAN network, they need to have unique IDs. The default ID is 1. To assign different IDs to each board, follow the method below:

1. Connect a single Tinymovr to the bus and launch Studio. The board will be assigned the default ID, 1, and will be accessible as tm1.

2. |gui| Change the ID

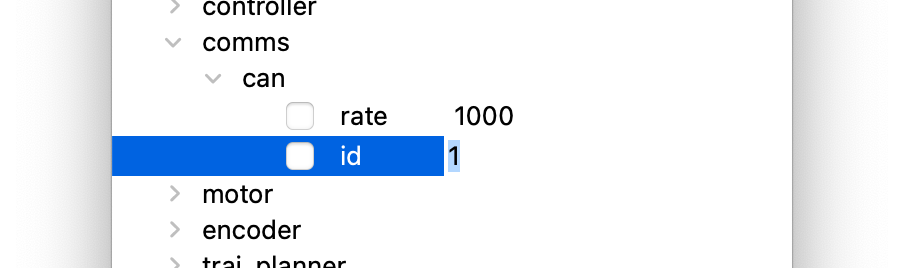
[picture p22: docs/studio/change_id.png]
Change CAN bus node ID using the GUI


The board will be discovered with the new ID. Studio GUI will rescan, discover the new node, and remove the old instance.

2. |cli| Change the ID

.. code-block:: python

    tm1.comms.can.id = x

where x is the desired ID. You can assign IDs in the range 1-1024.

The board will be discovered with the new ID. Relaunch Studio CLI to remove the old board instance. 

3. |gui| Save configuration.

Save configuration using the GUI

3. |cli| Save configuration.

.. code-block:: python

    tm1.save_config()

4. Power down or reset the board. Tinymovr is now ready to use with the new ID.

.. _command-line-options:

Command-line options
####################

Tinymovr Studio supports the following command line options.

``--bus=<bus>``
=======================

The --bus option specifies a CAN bus type to use.

Example:

|gui|

.. code-block:: console

    tinymovr --bus=canine

|cli|

.. code-block:: console

    tinymovr_cli --bus=canine

All interfaces offered by python-can are supported.

``--chan=<chan>``
=================

The --chan options specifies a channel to use, optionally together with the --bus option. 

Example:

|gui|

.. code-block:: console

    tinymovr --bus=socketcan --chan=CAN0

|cli|

.. code-block:: console

    tinymovr_cli --bus=socketcan --chan=CAN0

By default, Tinymovr Studio will use slcan as the interface, and will search for CANAble/CANtact-type devices with slcan firmware. Such is the CANine adapter supplied with Tinymovr Servo Kits.

``--bitrate=<chan>``
====================

Specifies a bitrate in baud.

Example:

|gui|

.. code-block:: console

    tinymovr --bus=socketcan --bitrate=1000000

|cli|

.. code-block:: console

    tinymovr_cli --bus=socketcan --bitrate=1000000

By default, Tinymovr Studio will use 1000000 as bitrate.
We tested with 1000000, 500000 and 250000 baud.

Units
#####

Tinymovr Studio introduced physical units and quantities since v0.3.0. Units are introduced through the `Pint <https://pypi.org/project/Pint/>`_ package. Using units you will see all values that you query associated with a unit, which forms a physical quantity.

|gui|

In the GUI, units are displayed by default in any quantity that supports them. For instance:

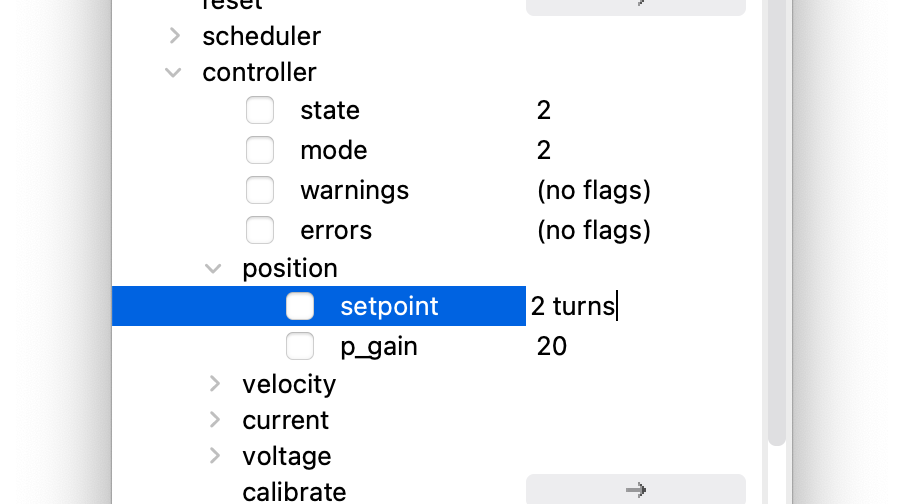
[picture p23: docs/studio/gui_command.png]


You can set any quantity supporting units by specifying the desired compatible unit next to the quantity you want to set. For instance, to set the position setpoint:

|cli|

In the CLI, units are displayed whenever a quantity that supports them is printed:

.. code-block:: python

    In [1]: tm1.encoder.pos_estimate
    Out[1]: 0.0 <Unit('tick')>

You can also set quantities in any (defined) unit you wish. For instance:

.. code-block:: python

    In [1]: tm1.controller.pos_setpoint = 2.0 * rad

The above will set the rotor position to 2 radians from the initial position. Similarly for velocity:

.. code-block:: python

    In [1]: tm1.controller.vel_setpoint = 3.0 * rad / second

Will set velocity to 3 radians/second. If not unit is used in setting a value, the default units will be assumed, in the above cases ticks and ticks/second.

The ureg object is the unit registry, and it is that which holds all unit definitions. You can use it to do all sorts of cool stuff such as doing conversions, defining your own shortcuts or even new units.

For instance, to define a few frequently used shortcuts in a program:

.. code-block:: python

    from avlos import get_registry
    ureg = get_registry()
    mA = ureg.milliampere
    rad = ureg.radian
    s = ureg.second

Then you can use the defined shortcuts to intuitively set values, such as a position setpoint with velocity and current feed-forwards:

.. code-block:: python

    tm1.controller.pos_setpoint = 2*PI * rad
    tm1.controller.vel_setpoint = PI * rad/second
    tm1.controller.cur_setpoint = 1.5 * ampere

Take a look at the :ref:`api-reference` for default units used in each command.

For more information on units and their usage, take a look at `Pint's documentation <https://pint.readthedocs.io/en/stable/>`_

Socketcan & Linux
#################

You can use a socketcan-enabled CAN adapter with Tinymovr Studio. The CANine adapter supplied with Tinymovr Servo Kits supports Socketcan natively with the alternative Candlelight Firmware. To connect to a Socketcan device, run Studio as follows:

|gui|

.. code-block:: console

    tinymovr --bus=socketcan --chan=CAN0

|cli|

.. code-block:: console

    tinymovr_cli --bus=socketcan --chan=CAN0

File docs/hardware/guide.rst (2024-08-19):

.. _hardware-setup:

**************
Hardware Setup
**************

Requirements
############

1. A 3-phase brushless motor (see below for supported types)
2. A diametrically magnetized sensor magnet (included with Tinymovr), mounted firmly on the motor shaft.
3. A means to talk CAN Bus, such as CANine or a Canable-compatible adapter.
4. A mechanical rig that ensures firm connection between the Tinymovr PCB and the brushless motor. Designs that can be 3D printed are available.

The Tinymovr Servo Kit includes all of the above, except for the CANine adapter, in a ready to use kit.

Supported Motor Types
#####################

Tinymovr R5.x and R3.x
**********************

Most three-phase pancake-style outrunners can be used with Tinymovr R5. While there is a lot of variation between motors of even the same size and external appearance, as a general rule-of-thumb motors ranging from 40mm outer diameter to 110mm should work fine with Tinymovr.

For a good quality and affordable option, take a look at our own `Tinymovr Motors <https://tinymovr.com/5208_motor>`_.

Tinymovr M5.x
*************

Most gimbal motors can be used with Tinymovr M5. Gimbal motors are essentially outrunners with high resistance (they have more turns). You can read more about gimbal motors in :ref:`gimbal-introduction`. Note that, to control gimbal motors with Tinymovr M5, you do not have to (in fact, should not) use Gimbal mode. Tinymovr M5 is capable of accurately sensing current at a lower scale, which is compatible with gimbal motors.

.. note::
   * Tinymovr expects a motor with sinusoidal back-EMF. Most brushless outrunners (including gimbal motors) have sinusoidal back-EMF. If uncertain and you have access to an oscilloscope, you can hook up the motor phases to the scope channels and check out the back-EMF for yourself. 

   * Motors with trapezoidal back-EMF can also be controlled, but control will be sub-optimal. The trapezoidal back-EMF will appear as residual in the dq frame, as a result it will be much harder for the current controller to regulate phase currents. The tangible result is that the motor may exhibit increased noise and vibration while running.

Limitations
***********

Tinymovr controllers are designed with certain limitations in terms of motor internal resistance and inductance, to ensure optimal closed loop current control performance.

.. list-table:: Motor Limits
   :header-rows: 1

   * - Controller Version
     - Phase Resistance (ohms)
     - Phase Inductance (henries)
   * - Tinymovr R5.x and R3.x
     - 0.01 to 1.0
     - 5e-6 to 1e-3
   * - Tinymovr M5.x
     - 0.5 to 20.0
     - 1e-5 to 1e-2

Note that motors with parameters outside this range will result in calibration failing. Ensure that the motors you select adhere to these parameters for the best operational experience. You can still use motors outside this range with open loop current control, through :ref:`enabling-gimbal-mode`.

Mechanical Setup
################

Mounting Motor and Tinymovr
***************************

The most important aspect of a correct setup is to ensure the controller is properly positioned in relation to the sensor magnet. We assume that the center of the PCB, where the angle sensor IC is located, is located coaxially to the motor shaft, and thet the sensor magnet is at the end of the shaft (check out the diagrms below). In addition, the distance from the sensor magnet to the sensor IC should be less than 2mm (less than 1mm if you are mounting the PCB packwards, i.e. the sensor IC is facing away from the magnet).

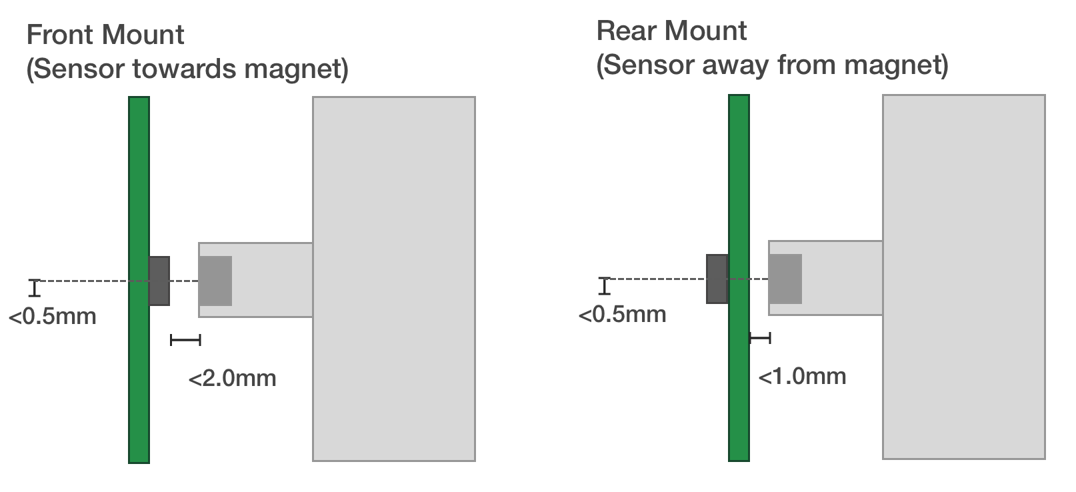
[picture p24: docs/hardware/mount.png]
Tinymovr and motor mechanical mounting


  Tinymovr and motor mechanical mounting

A `3D printable sensor magnet jig <https://github.com/yconst/Tinymovr/blob/master/hardware/misc/magnet_jig.stl>`_ is available, suitable for 6mm disc magnets and 14, 19, 25 and 30mm motor hole diameters.

.. note::
   For safety reasons, you should always ensure the motor & controller assembly are secured to a stable surface before operation. The motor rotor may experience high acceleration that may cause damage or injury if not secured properly.

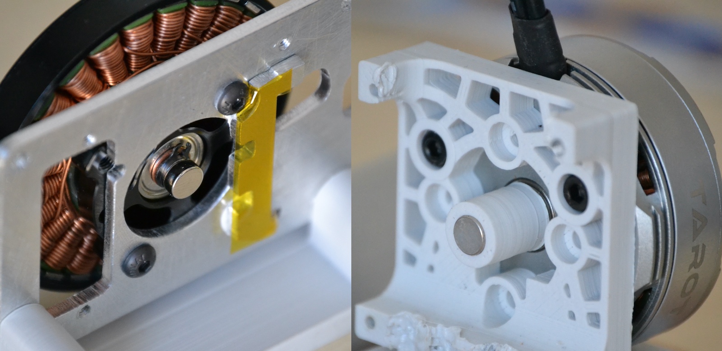
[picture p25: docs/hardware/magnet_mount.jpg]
Left: Magnet mount directly on shaft. Right: Magnet mount using 3d-printed holder.


  Left: Magnet mount directly on shaft. Right: Magnet mount using 3d-printed holder.

Sensor Magnet and Mounting Tips
-------------------------------

* Unless using an external sensor (e.g. Hall effect sensor), Tinymovr requires proximity to the sensor magnet to operate. If the magnet is not in close proximity, an error will be raised upon power up, preventing any further action (calibration, closed loop control).

* Ensure the sensor magnet is firmly attached to the motor shaft, otherwise it may slip out of sync. Use strong adhesive to secure.

* It is possible to have the magnet on the rear side of the PCB, i.e. opposite of the magnet sensor IC, but the gap needs to be reduced to account for the PCB thickness. This has been verified by MPS in a forum post [1]_, quoted below: 
  *[...] this type of arrangement is possible, what really matters in the end is that there is enough magnetic field reaching the sensor.
  Of course the minimum distance is imposed by the thickness of the PCB, so it puts some constraints on the design, that you have to take into account when choosing the magnet (you can use our online simulation tool for that). But as long as the PCB is not acting as a magnetic shield (due to copper plane), then it is fine.*

* Calibration needs to be performed without any loads on the motor. If the motor is coupled to a load, the sensor offset angle may not be determined correctly, leading to a sub-optimal setup.

* For Tinymovr R3.3, adjust your termination resistor DIP switch (if needed) before putting together your actuator, to avoid needing to disassemble it for adjustment later on. See also :ref:`connecting-data`.

.. _electrical-setup:

Electrical Setup
################

Electrical setup comprises three main parts: Motor connection, data connection and power connection. Below is a diagram with the electrical connection scheme.

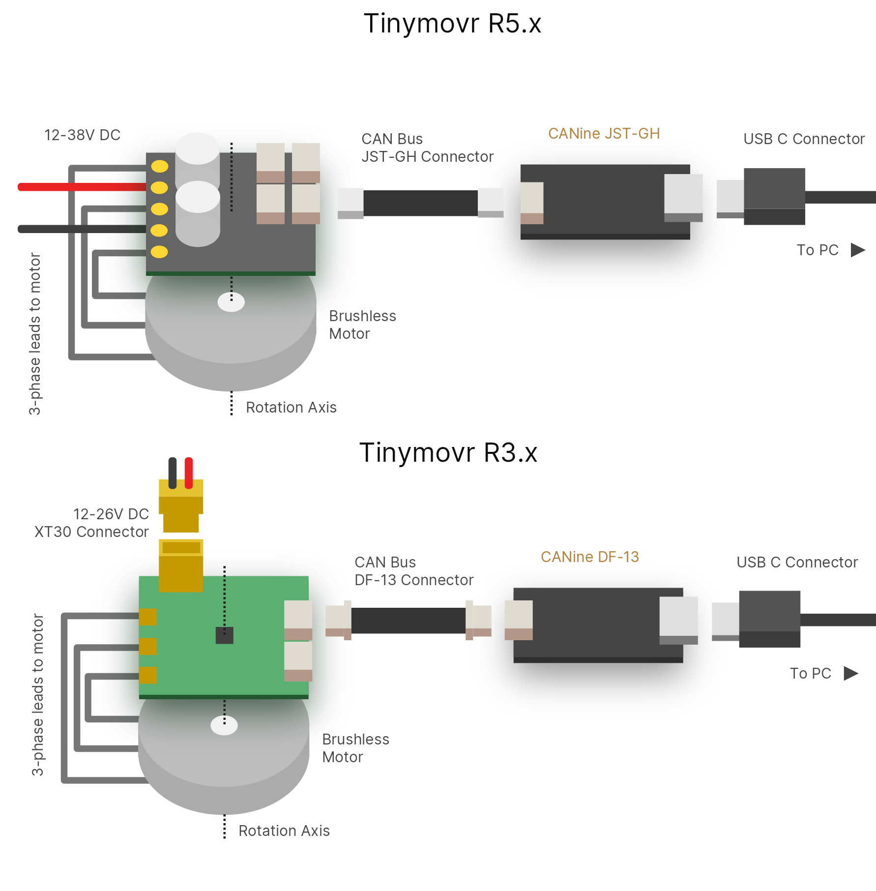
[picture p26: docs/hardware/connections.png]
Tinymovr power and data connection diagram


Connecting Motor
################

Connect the three motor phases to the three terminals on Tinymovr. The order of connection is not important, and motor direction will be determined during motor/sensor calibration.

* Tinymovr R3.x: The motor leads can be connected by soldering on the PCB. 

* Tinymovr R5.x: The leads can be connected by soldering on the PCB, or you can solder a screw terminal block and secure the motor leads on the block.

* Tinymovr M5.x: The leads can be connected by soldering on the PCB.

.. _connecting-data:

Connecting Data
###############

Connect the CAN bus header to one of the two CAN sockets on the board. It is not important which one you choose. If this is a terminal node in the CAN network, you may need to use a termination resistor, as follows:

* Tinymovr R3.x: flip ONLY the DIP switch labelled "CAN 120R" to on to enable the 120Ω termination resistor. 

* Tinymovr R5.x: you will need to provide an external 120Ω termination resistor.

* Tinymovr M5.x: you will need to provide an external 120Ω termination resistor.

In small setups with few nodes and short wires, it is better to enable just a single termination resistor, either on one Tinymovr board or on the CAN adapter. In setups with many nodes and long cables, you may need to enable termination resistors in both terminal nodes. A typical CAN driver has an “open-drain” output structure, meaning that the dominant edge is actively driven and the recessive edge is not. Therefore, properly terminating the bus is very important because it ensures that the recessive edge decays properly, and in time for the next bit's sample point [2]_.

.. warning::
   The UART pins in Tinymovr R5.1 have the silkscreen reversed. If you are planning to use UART with R5.1, consult :ref:`r51-erratum-1`. 

.. _connecting-power:

Connecting Power
################

* Tinymovr R3.x can be powered from a 12-26V (3S-6S) power source.

* Tinymovr R5.x can be powered from a 12-38V (3S-9S) power source.

* Tinymovr M5.x can be powered from a 12-38V (3S-9S) power source.

With the power source off/disconnected, connect the power leads observing correct polarity. Turn on/connect the power source. Upon successful power-up, the onboard LED should light up.

.. note::
   Each Tinymovr board has a capacitance of around 500μF (R3.x) / 240μF (R5) / 50μF (M5). Such capacitance can introduce significant inrush current upon power-on, especially if several boards are connected to the same power supply. To prevent damage to components from overcurrent, the use of an inrush current limiter or a current-limited power supply is advised. We offer a `Power Distribution and protection device <https://tinymovr.com/products/dianome>`_ which is suitable for this task.

.. _daisy-chain:

Connecting Multiple Nodes (Daisy-Chaining)
##########################################

Multiple nodes can be connected in a single CAN Bus network by means of daisy-chaining. Tinymovr R5 and Tinymovr M5 offer two CAN Bus ports for this purpose, which makes it easy to daisy-chain units. Note that for networks with long cable lengths, you may need termination on both ends. On one end this can be achieved with the onboard termination resistor of CANine, but on the other end you will have to provide your own.

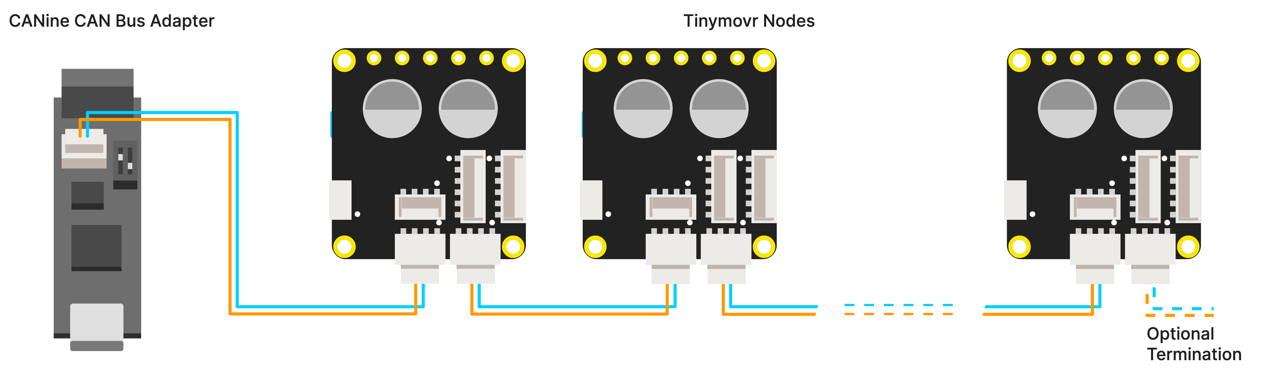
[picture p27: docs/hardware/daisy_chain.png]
Connecting multiple nodes by daisy-chaining


.. [1] MPS forum post on mounting MA702 and magnet on opposite sides of PCB: https://forum.monolithicpower.com/t/mounting-ma702-and-magnet-on-opposite-sides-of-pcb/1609
.. [2] Split Termination, Texas Instruments. Available at `https://www.ti.com/document-viewer/lit/html/SSZTB40#:~:text=for%20each%20termination.-,Split%20Termination,typically%20between%201%2D100nF`.

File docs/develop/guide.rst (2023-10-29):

**********
Developers
**********

Overview
########

This document provides a guide for setting up a development environment for developing for Tinymovr, including firmware and client software (Studio). 

Hardware Connections
####################

For proper debugging capabilities you will need a Segger J-Link adapter. Unfortunately original J-Link adapters are quite expensive. A more affordable option is the J-Link EDU adapter at around $60 or the J-Link EDU mini adapter at around $20. In addition, there are J-Link clones that can be purchased for very low prices on ebay or Aliexpress. However, reliability of these clones is not guaranteed, and we do not provide support when using these clones.

With the board and J-Link adapter powered off, connect the J-Link to Tinymovr as shown below:

Connection directly to J-Link adapter for R3.x:

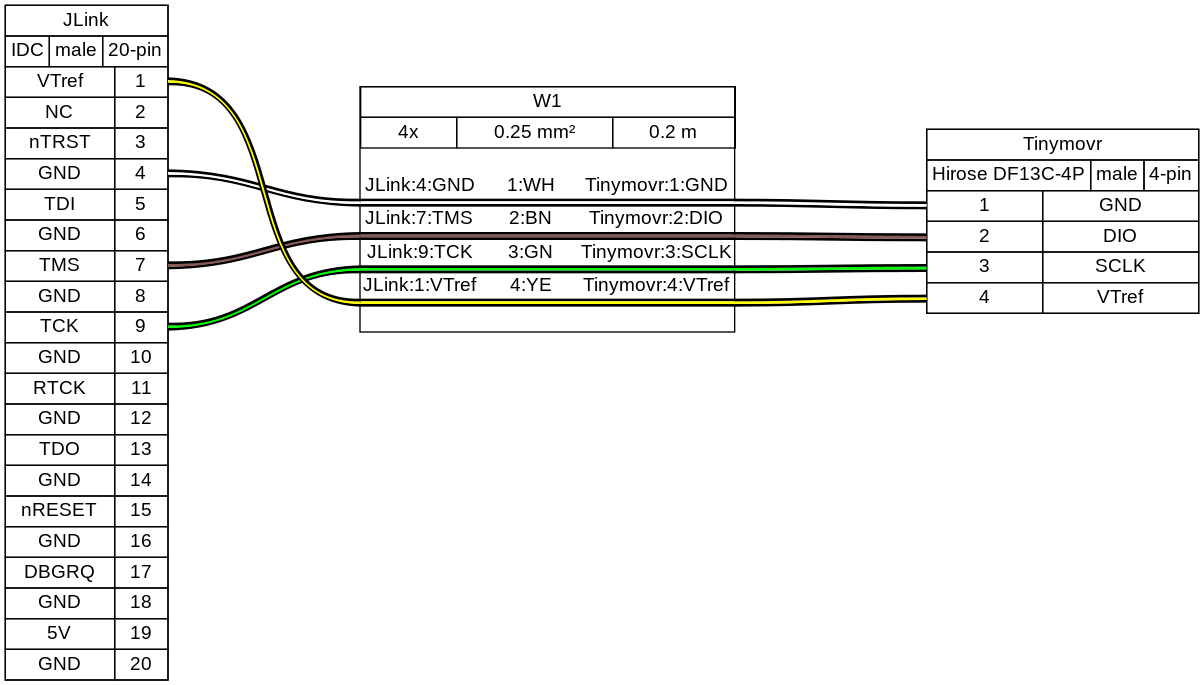
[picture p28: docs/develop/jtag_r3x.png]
Tinymovr R3.x pin header connection


Connection directly to J-Link adapter for R5:

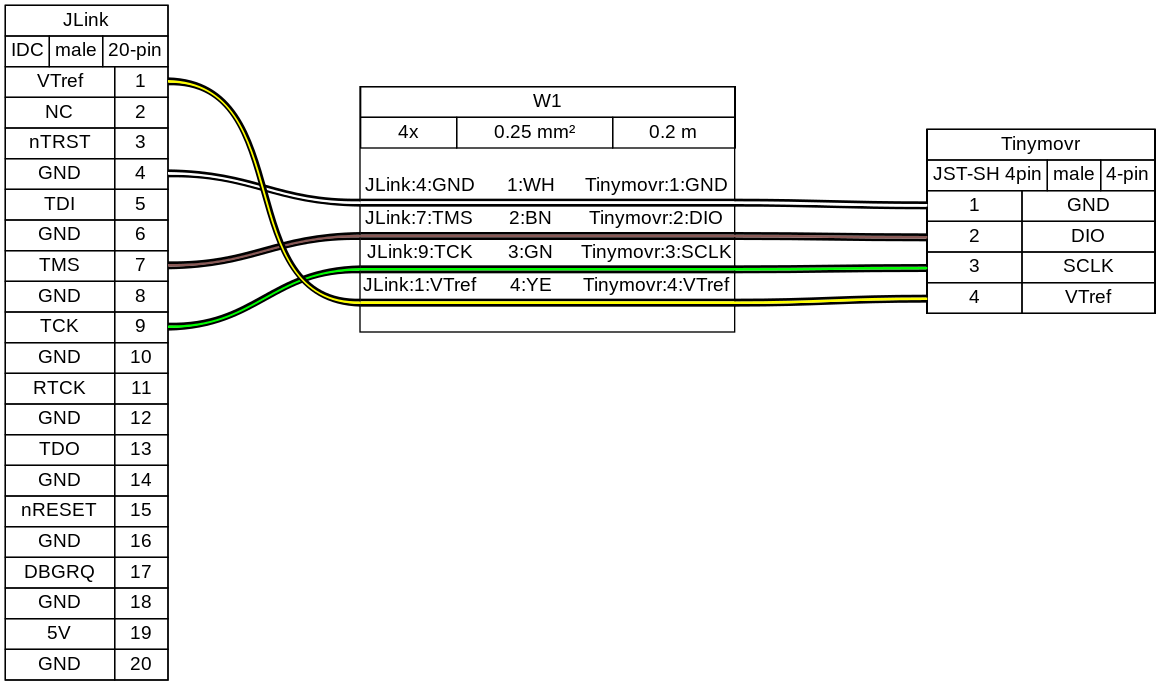
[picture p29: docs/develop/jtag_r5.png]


Connection with SWD adapter (e.g. isolator) for R3.x:

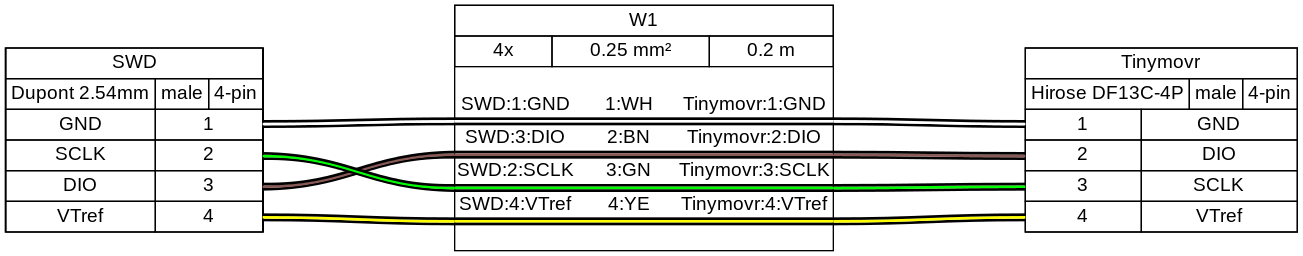
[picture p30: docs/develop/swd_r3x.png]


Connection with SWD adapter (e.g. isolator) for R5:

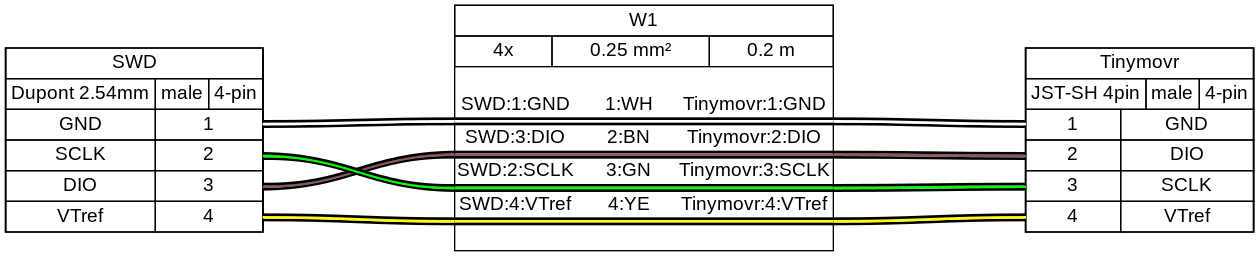
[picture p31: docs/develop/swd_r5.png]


(diagrams made with `Wireviz <https://github.com/formatc1702/WireViz>`_)

As of Tinymovr 1.0.1, it is no longer necessary to patch the ``JLinkDevices.xml`` file with the PAC additions, in order for JLinkGDBServer to work properly. Relevant files are included in the repo.

.. _develop-preparation:

Preparation
###########

First, clone the Tinymovr repo:

.. code-block:: console

    git clone https://github.com/yconst/Tinymovr

The Tinymovr repo includes the firmware source code and supporting files, however the PAC55xx SDK is not included due to licensing restrictions imposed by Qorvo. Thus, you will need to `download it from the Qorvo website <https://www.qorvo.com/products/p/PAC5527#evaluation-tools>`_, where you will need to supply your email.

The file comes in a zipped installer exe (!), which all it does is extract the contents to a directory. Navigate to the extracted files directory and copy the 'pac55xx_sdk' directory inside the Tinymovr repo:

.. code-block:: console

    cp -r <pac55xx_sdk_location> <tinymovr_location>/firmware/pac55xx_sdk/

In any case, the target directory should be named ``pac55xx_sdk``. The above copy command ensures this.

Now you have the required PAC SDK almost ready. There is a small patch that you will need to apply in the pac55xx_sdk directory. It is suggested to use the `Python patch package <https://pypi.org/project/patch/>`_, which is cross-platform. If you do not have the package, install using pip:

.. code-block:: console

    pip3 install patch

Then:

.. code-block:: console

    cd <tinymovr_location>/firmware
    python3 -m patch sdk_patch.patch

As a final step, install the `GNU Arm Embedded Toolchain <https://developer.arm.com/tools-and-software/open-source-software/developer-tools/gnu-toolchain/gnu-rm/downloads>`_. 

If you are in Windows you will also need to install GNU make. This is rather easy in Windows 10 or later:

.. code-block:: console

    choco install make

.. _develop-setting-up-vscode:

Using VSCode
############

Our development environment for Tinymovr utilizes VSCode and is designed with cross-platform compatibility in mind. We support all major operating systems: Linux, MacOS, and Windows. This method allows for a unified approach to building, flashing, and debugging firmware.

We take great pride in creating this in-house, cross-platform development solution, as an alternative to the official Windows-only solution, providing enhanced flexibility and simplifiyng the process of developing for Tinymovr across multiple platforms.

Configuring
***********

You'll need to configure the path to the JLink debug server in ``.vscode/launch.json``. The configuration blocks look like this:

.. code-block:: javascript
  
    "windows": {
        // Update the path below as necessary
        "serverpath": "C:\\Program Files\\SEGGER\\JLink\\JLinkGDBServerCL.exe" 
    },
    "linux": {
        // Update the path below as necessary
        "serverpath": "/opt/SEGGER/JLink/JLinkGDBServer" 
    }

There are several instances of such blocks in the file that need to be updated.

Building
********

To try out a test build from within VSCode select ``Terminal -> Run Task...`` from the menu bar, and select ``Clean and Build Project (Debug)``.

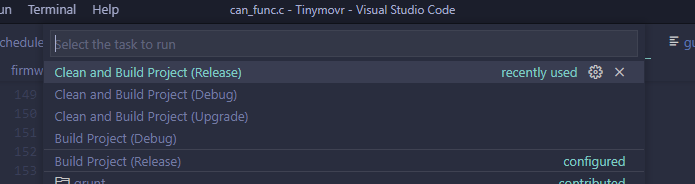
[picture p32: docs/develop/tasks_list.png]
Task selector


Tinymovr implements board revision selection using an input menu with a few predefined choices.

Board revision selector

Select the board revision against which you are compiling from the list. The build process will start, it usually takes less than half a minute. After it finishes, you should end up with a ``build/`` directory inside ``firmware/`` and there you should see the files ``tinymovr_fw.elf``, ``tinymovr_fw.hex`` and ``tinymovr_fw.bin``.

More about Hardware Revisions
-----------------------------

Tinymovr passes the ``BOARD_REV_XX`` argument regarding the board revision to the compiler. This is used in the firmware to configure the hardware accordingly. Invoking a make command with the REV argument is as follows:

.. code-block:: console

    make debug REV=R5

Currently the following hardware revision values are supported:

- R32
- R33
- R50
- R51
- R52
- M5

Flashing and Debugging
**********************

Before debugging, make sure the J-Link drivers and software is installed. The drivers and software, together with instructions, can be found in the `Qorvo website <https://www.qorvo.com/products/p/PAC5527#evaluation-tools>`_, under the download 'Segger J-Link Support'. This download includes a nacessary patch to enable J-Link to work with Qorvo devices. Instructions on how to apply the patch are included in the download.

The Tinymovr repo includes all VSCode settings configured, except for the JLink ``serverpath`` variable in ``launch.json``, which you'll need to update to reflect your system. Note that there are multiple instances in the file, you'll need to update all of them.

We offer various VSCode launch configurations to suit different development and debugging tasks, including remote Tinymovr flashing debugging using a remote JLink server. These are are briefly outlined below.

Rebuild Debug and Start Session
-------------------------------

This is a convenience configuration that does a clean debug build, flashes it and launches a debug session. After a while the debug session should start and you should see a screen like below:

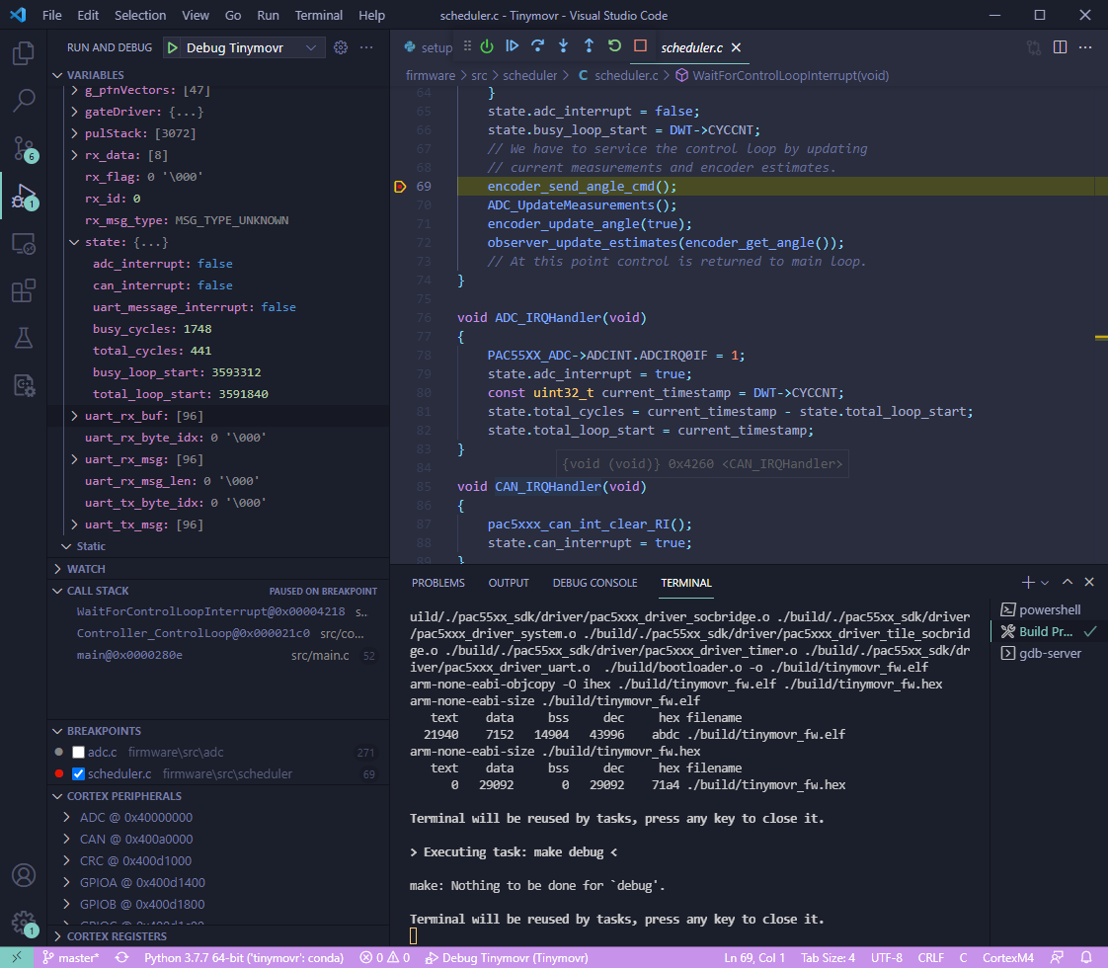
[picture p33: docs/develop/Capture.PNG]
Tinymovr firmware debug session using VSCode


Rebuild Release and Flash
-------------------------

This is a convenience configuration that does a clean release build and flashes it to Tinymovr.

Flash Built Binary and Start Session
------------------------------------

This will flash an already built binary and start a debug session. It assumes a binary already exists in the ``firmware/build/`` directory.

Flash Built Binary
------------------

This will flash an already built binary. It assumes a binary already exists in the ``firmware/build/`` directory.

Attach to Target
------------------

This will attach to an already running target.

Flash Built Binary and Start Remote Session
-------------------------------------------

This will connect to a remote JLink server, upload the firmware to the remote Tinymovr device, and start a remote debug session. You will need to have a JLink Server configured on a network attached device, such as a Raspberry Pi (`here is a good guide on how to do that <https://blog.feabhas.com/2019/07/using-a-raspberry-pi-as-a-remote-headless-j-link-server/>`_). You will also need to input the remote device's IP address to the ``ipAddress`` field of the ``launch.json`` file.

Note that the launch configurations can be selected and initiated from the VSCode "Run and Debug" pane. You can also hit ``F5`` to launch the currently selected configuration.

Congrats! You are now fully set to start with Tinymovr development!

Using Eclipse
#############

Eclipse is no longer supported. Consider :ref:`develop-setting-up-vscode` instead.

Setup Studio for Development
############################

Tinymovr Studio is a Python application and as such can be easily set up to facilitate development. The approach is to use ``pip`` to install Tinymovr in develop mode, from a local copy of the (``git repo <https://github.com/tinymovr/Tinymovr>``_). This allows any changes you make to the local code to be immediately available when you run the executable (``tinymovr``, ``tinymovr_cli``, or ``tinymovr_dfu``).

.. note::
   We recommend installing Tinymovr in a virtual environment. `Here is a quick tutorial on how to setup a virtual environment using Conda <https://conda.io/projects/conda/en/latest/user-guide/getting-started.html#managing-environments>`_.

Clone the Tinymovr repo as outlined in the first step of :ref:`develop-preparation`. Then:

.. code-block:: console

    cd <tinymovr_location>/studio/Python/
    pip3 install -e .

or to enable GUI support:

.. code-block:: console

    pip3 install -e .[GUI]

This will install the Tinymovr Studio in develop mode. Now, ``tinymovr``, ``tinymovr_cl`i`` and ``tinymovr_dfu`` will use the local Tinymovr Studio code.

Happy coding!

Custom Device Definitions
#########################

Tinymovr uses YAML files for device specification (the spec). Device spec files reside in ``{tinymovr_package_dir}/studio/Python/tinymovr/specs/``. This is where files covering Tinymovr firmware 1.3.x to 1.6.x are situated by default. 

You can add custom device spec files in this directory to tell Tinymovr Studio GUI, CLI and library how to communicate with custom devices. For instance, assuming that you have installed Tinymovr Studio using ``pip3``, you will need to find the directory of the tinymovr package first using the command below:

Windows

.. code-block:: console

    python -c "import os, tinymovr; print(os.path.dirname(tinymovr.__file__))"

Macos and Linux

.. code-block:: console

    python3 -c "import os, tinymovr; print(os.path.dirname(tinymovr.__file__))"

Then, paste your custom spec file to ``{tinymovr_package_dir}/studio/Python/tinymovr/specs/``. Tinymovr should correctly discover your custom device.

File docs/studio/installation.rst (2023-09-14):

.. _studio-installation:

*******************
Studio Installation
*******************

Tinymovr Studio is a cross-platform GUI application, CLI application, and Python library that offers easy access to all of Tinymovr's functionality. 

Studio requires Python 3.9 or newer.

Preparation
###########

If using Windows with a CANtact-compatible CAN Bus adapter, such as CANine, you will need to install an .inf file to enable proper device naming. You can `download the inf file here <https://canable.io/utilities/windows-driver.zip>`_. Extract the archive, right click and select Install.

Using pip
#########

This is the most straightforward method to install Tinymovr studio and have access to hardware. The following command will install Tinymovr with the dependencies required for the Qt-based Tinymovr Studio GUI:

.. code-block:: console

    pip3 install 'tinymovr[GUI]'

If you don't plan to use the GUI, you can skip installing some dependencies using the following installation command instead:

.. code-block:: console

    pip3 install tinymovr

.. code-block:: console

    tinymovr

You should now be looking at the Tinymovr GUI. Alternatively, to start the IPython-based Command Line Interface (CLI):

.. code-block:: console

    tinymovr_cli

Anaconda Installation
---------------------

Tinymovr can be installed inside a Virtualenv or Anaconda environment. 

With Anaconda, create a new environment:

.. code-block:: console

    conda create --name tinymovr python=3.10 -y
    conda activate tinymovr

Alternatively you can use any Python version >= 3.9.

Then simply install and run Tinymovr:

.. code-block:: console

    pip install 'tinymovr[GUI]'
    tinymovr

Using git clone
###############

.. note::
   The master branch of the Github repository represents the state of art of development, and it may contain bugs.
   For a stable version, especially if you are starting with the project, please consider installing Tinymovr Studio using pip as shown above.

First clone the Tinymovr repo to a local directory:

.. code-block:: console

    git clone https://github.com/yconst/Tinymovr

Then cd to the cloned repo directory and install in developer mode:

.. code-block:: console

    cd Tinymovr/studio/Python
    pip3 install -e .

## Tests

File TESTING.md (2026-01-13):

# Tinymovr Testing Guide

**Purpose**: Testing infrastructure, practices, and requirements for Tinymovr development.

**Target Audience**: Developers and AI agents writing tests for firmware or Python client.

## Test Types

### 1. Simulation Tests (No Hardware Required)

**Purpose**: Logic validation, protocol testing, unit tests that don't require physical hardware.

**Location**: [studio/Python/tests/test_simulation.py](studio/Python/tests/test_simulation.py)

**Running**:
```bash
cd studio/Python
python -m unittest tests/test_simulation.py
```

**When to Use**:
- Testing protocol hash computation
- Validating spec parsing
- Testing serialization/deserialization logic
- Unit testing helper functions

### 2. Hardware-in-the-Loop (HITL) Tests

**Purpose**: End-to-end testing with real Tinymovr hardware.

**Requirements**:
- Tinymovr board (R3.x, R5.x, or M5.x)
- Motor connected (type depends on board)
- CAN interface (CANine, slcan, socketcan, etc.)
- Motor must be free to rotate

**Location**: [studio/Python/tests/](studio/Python/tests/)

**Running**:
```bash
cd studio/Python

# Basic hardware tests
pytest -m hitl_default

# Verbose output
pytest tests/test_board.py -v

# Specific test
pytest tests/test_board.py::TestTinymovr::test_position_control -v
```

### 3. Sensor-Specific Tests

**Purpose**: Testing specific encoder types.

**Markers**:
- `@pytest.mark.sensor_amt22` - Requires AMT22 encoder
- `@pytest.mark.sensor_as5047` - Requires AS5047 encoder
- `@pytest.mark.sensor_hall` - Requires Hall effect sensors

**Running**:
```bash
pytest -m sensor_as5047   # Only AS5047 tests
pytest -m sensor_amt22    # Only AMT22 tests
pytest -m sensor_hall     # Only Hall sensor tests
```

### 4. End-of-Line (EOL) Tests

**Purpose**: Comprehensive production testing.

**Marker**: `@pytest.mark.eol`

**Running**:
```bash
pytest -m eol
```

**Characteristics**:
- Extensive coverage
- Tests all major features
- Validates calibration accuracy
- Checks error handling
- Long duration (15+ minutes)

### 5. DFU/Bootloader Tests

**Purpose**: Firmware update and bootloader testing.

**Marker**: `@pytest.mark.dfu`

**Running**:
```bash
pytest -m dfu
```

## Test Markers Reference

### Pytest Markers

```python
import pytest

@pytest.mark.hitl_default        # Basic hardware test
@pytest.mark.sensor_amt22        # Requires AMT22 encoder
@pytest.mark.sensor_as5047       # Requires AS5047 encoder
@pytest.mark.sensor_hall         # Requires Hall sensors
@pytest.mark.eol                 # End-of-line comprehensive test
@pytest.mark.dfu                 # Bootloader/firmware update test
```

### Running Multiple Markers

```bash
# Run hitl_default AND sensor_as5047 tests
pytest -m "hitl_default or sensor_as5047"

# Run all except EOL tests
pytest -m "not eol"

# Run only AS5047 EOL tests
pytest -m "eol and sensor_as5047"
```

## Writing Tests

### Test Structure (Base Class)

All HITL tests inherit from [TMTestCase](studio/Python/tests/tm_test_case.py):

```python
import pytest
from tests.tm_test_case import TMTestCase

class TestMyFeature(TMTestCase):
    """Test suite for my feature"""

    @pytest.mark.hitl_default
    def test_feature_basic(self):
        """Test basic functionality"""
        # Verify initial state
        self.check_state(0)  # Should be IDLE

        # Calibrate if needed
        self.try_calibrate()

        # Test your feature
        self.tm.my_endpoint = 123.0
        result = self.tm.my_endpoint

        self.assertAlmostEqual(result, 123.0, delta=0.1)

    @pytest.mark.hitl_default
    def test_feature_edge_case(self):
        """Test edge case handling"""
        self.try_calibrate()

        # Test out-of-range input
        with self.assertRaises(Exception):
            self.tm.my_endpoint = 99999.0
```

### TMTestCase Helper Methods

**Key Methods**:
- `self.tm` - Device instance (automatically created in setUp)
- `self.check_state(expected_state)` - Assert controller state
- `self.try_calibrate()` - Calibrate if not already calibrated
- `self.wait_for_calibration()` - Wait for calibration to complete

**Example Usage**:
```python
# Check state
self.check_state(0)  # Verify IDLE
self.check_state(2)  # Verify CL_CONTROL

# Calibrate
self.try_calibrate()  # Only calibrates if needed

# Standard assertions
self.assertEqual(actual, expected)
self.assertAlmostEqual(actual, expected, delta=0.01)
self.assertGreater(value, threshold)
self.assertLess(value, threshold)
```

### Test Naming Conventions

**Format**: `test_<feature>_<scenario>`

**Examples**:
```python
def test_position_control_basic(self):
    """Test basic position control"""
    pass

def test_position_control_trajectory(self):
    """Test position control with trajectory planner"""
    pass

def test_calibration_resistance_range(self):
    """Test resistance calibration with out-of-range motor"""
    pass

def test_error_handling_overcurrent(self):
    """Test automatic transition to IDLE on overcurrent"""
    pass
```

### Example: Complete Test

```python
import pytest
from tests.tm_test_case import TMTestCase

class TestPositionControl(TMTestCase):
    """Test position control functionality"""

    @pytest.mark.hitl_default
    def test_position_setpoint_tracking(self):
        """Test position setpoint tracking accuracy"""
        # Setup
        self.check_state(0)
        self.try_calibrate()

        # Enter position control mode
        self.tm.controller.position_mode()
        self.check_state(2)  # CL_CONTROL

        # Test multiple setpoints
        for setpoint in [0, 5000, -5000, 10000]:
            self.tm.controller.position.setpoint = setpoint

            # Wait for settling
            time.sleep(0.5)

            # Check tracking accuracy
            position = self.tm.sensors.user_frame.position_estimate
            error = abs(position - setpoint)
            self.assertLess(error, 50, f"Tracking error too high: {error} ticks")

        # Return to idle
        self.tm.controller.idle()
        self.check_state(0)

    @pytest.mark.hitl_default
    def test_position_control_velocity_limit(self):
        """Test position control respects velocity limit"""
        self.try_calibrate()

        # Set low velocity limit
        self.tm.controller.velocity.limit = 10000  # ticks/s

        # Enter position control
        self.tm.controller.position_mode()

        # Command large position change
        self.tm.controller.position.setpoint = 50000

        # Monitor velocity during motion
        time.sleep(0.1)
        velocity = self.tm.sensors.user_frame.velocity_estimate

        # Velocity should not exceed limit
        self.assertLess(abs(velocity), 11000, "Velocity limit exceeded")
```

## Safety Testing Requirements

### For Control Loop Changes

If you modify control loop code, **all** of the following tests are required:

**Timing Tests**:
- [ ] Measure `tm.scheduler.load` < 3000 cycles (at 150 MHz)
- [ ] Test at maximum load (all features enabled)
- [ ] Verify no `SCHEDULER_WARNINGS_CONTROL_BLOCK_REENTERED`

**Multi-Board Tests**:
- [ ] Test on R5.x board (high-current)
- [ ] Test on M5.x board (gimbal)
- [ ] (Optional) Test on R3.x board if available

**Multi-Motor Tests**:
- [ ] Test with high-current motor (>5A rated)
- [ ] Test with gimbal motor (<5A rated)
- [ ] Test at different voltages (12V, 24V, 48V if applicable)

**Stability Tests**:
- [ ] Monitor for oscillations (visual and audible)
- [ ] Monitor for instability during acceleration/deceleration
- [ ] Check for overheating (>10 minute run at moderate load)
- [ ] Verify no erratic behavior at startup or shutdown

**Error Handling Tests**:
- [ ] Force overcurrent → Verify IDLE transition
- [ ] Force undervoltage → Verify IDLE transition
- [ ] Trigger watchdog → Verify IDLE transition
- [ ] Check all error flags set correctly

**Code**:
```python
# Timing test
load = tm.scheduler.load
assert load < 3000, f"Control loop overrun: {load} cycles"

# Error test
tm.controller.position_mode()
# Force error condition (e.g., set unrealistic setpoint)
time.sleep(1.0)
assert tm.controller.state == 0, "Did not transition to IDLE on error"
```

### For Calibration Changes

If you modify calibration code:

**Multi-Motor Tests**:
- [ ] Test on 5+ different motors (varying R, L, pole pairs)
- [ ] Verify calibration succeeds consistently (10+ attempts per motor)
- [ ] Check measured R/L values against known specifications
- [ ] Test with noisy power supply (introduce line noise)

**Fault Detection Tests**:
- [ ] Disconnect one phase → Verify abnormal voltage detection
- [ ] Short two phases → Verify abnormal voltage detection
- [ ] Test with wrong motor type → Verify out-of-range detection
- [ ] Test with obstructed shaft → Verify pole pair detection failure

**Code**:
```python
# Calibration accuracy test
tm.controller.calibrate()
time.sleep(5)  # Wait for completion

# Check results
R = tm.motor.R
L = tm.motor.L
pole_pairs = tm.motor.pole_pairs

# Verify within expected range (example for high-current motor)
assert 0.01 < R < 1.0, f"R out of range: {R} Ω"
assert 5e-6 < L < 1e-3, f"L out of range: {L} H"
assert 1 <= pole_pairs <= 24, f"Pole pairs out of range: {pole_pairs}"
```

### For Current Limit Changes

If you modify current limits:

**Incremental Tests**:
- [ ] Gradually increase current and verify trip at 1.5× limit
- [ ] Test at different bus voltages (12V, 24V, 48V)
- [ ] Monitor for hardware damage (smoke, overheating, burnt MOSFETs)
- [ ] Verify warning flags set correctly

**Hardware Monitoring**:
- [ ] Use thermal camera or temperature probe on MOSFETs
- [ ] Monitor bus voltage for droop under load
- [ ] Check for PCB discoloration or component damage
- [ ] Inspect motor windings for overheating

## Test Environment Setup

### Hardware Setup

**Minimal Setup** (for hitl_default):
1. Tinymovr board (R5.2 or M5.1 recommended)
2. Appropriate motor (high-current or gimbal)
3. Power supply (12-48V, adequate current rating)
4. CAN interface (CANine, PCAN-USB, etc.)
5. Motor mounted securely with free shaft rotation

**Extended Setup** (for sensor-specific tests):
- External encoder (AS5047, AMT22) with SPI connection
- Hall sensor motor with 3-wire Hall connections

### Software Setup

**Python Environment**:
```bash
cd studio/Python
pip install -e .              # Install Tinymovr client
pip install pytest            # Install test framework
```

**CAN Interface Configuration**:

**Linux (socketcan)**:
```bash
sudo ip link set can0 type can bitrate 1000000
sudo ip link set up can0
```

**CANine**:
```python
from tinymovr import init_router
from tinymovr.config import get_bus_config
import can

params = get_bus_config(["canine"], bitrate=1000000)
init_router(can.Bus, params)
```

### Device Configuration

**Before Running Tests**:
```python
from tinymovr import create_device

tm = create_device(node_id=1)

# Check firmware version
print(f"Firmware: {tm.fw_version}")
print(f"Protocol hash: {tm.protocol_hash}")

# Check board info
print(f"Board: {tm.board}")

# Erase config for clean state (optional)
tm.erase_config()
tm.reset()
```

## Debugging Failed Tests

### Common Failures

**1. Device Not Found**

**Symptom**:
```
IncompatibleSpecVersionError: Device found, but incompatible
```

**Causes**:
- Protocol hash mismatch (firmware vs. Python client)
- CAN interface not configured
- Wrong node ID
- Device not powered

**Debug**:
```python
# Check protocol hash
print(f"Device hash: {tm.protocol_hash}")
print(f"Expected: 641680925")  # Current v2.3.x hash

# Check CAN bus
import can
bus = can.Bus(interface='socketcan', channel='can0', bitrate=1000000)
print(bus.recv(timeout=1.0))  # Should see heartbeat messages
```

**2. Calibration Fails**

**Symptom**:
```
AssertionError: Motor errors: 16 (ABNORMAL_CALIBRATION_VOLTAGE)
```

**Causes**:
- Motor phases not connected
- Wrong motor type for board (gimbal on R5 board)
- Power supply unstable
- Motor shaft obstructed

**Debug**:
```python
# Read calibration details
print(f"Vbus: {tm.Vbus} V")
print(f"I_cal: {tm.motor.I_cal} A")
print(f"R: {tm.motor.R} Ω")
print(f"Motor errors: {tm.motor.errors}")

# Check expected ranges (R5 board, high-current motor)
# R should be 0.01-1.0 Ω
# L should be 5-1000 μH
```

**3. Position Control Unstable**

**Symptom**: Motor oscillates around setpoint

**Causes**:
- Gains too high
- Encoder noise
- Mechanical resonance
- Current limit too low

**Debug**:
```python
# Check gains
print(f"Position gain: {tm.controller.position.gain}")
print(f"Velocity gain: {tm.controller.velocity.gain}")

# Check limits
print(f"Current limit: {tm.controller.current.Iq_limit} A")
print(f"Velocity limit: {tm.controller.velocity.limit} ticks/s")

# Monitor loop performance
print(f"Scheduler load: {tm.scheduler.load} cycles")
```

**4. Timing Overruns**

**Symptom**:
```
SCHEDULER_WARNINGS_CONTROL_BLOCK_REENTERED
```

**Causes**:
- Control loop code too slow
- Missing `TM_RAMFUNC` annotation
- Using `double` instead of `float`
- Blocking operations in control loop

**Debug**:
```python
load = tm.scheduler.load
print(f"CPU load: {load} / 7500 cycles ({load/7500*100:.1f}%)")

# Should be <3000 cycles (40%)
# >5000 cycles indicates serious problem
```

## Continuous Integration

### Test Selection for CI

**Fast Tests** (run on every commit):
```bash
pytest -m "not hitl_default and not eol"  # Simulation tests only
```

**Hardware Tests** (run on hardware testbed):
```bash
pytest -m hitl_default  # Basic HITL tests (~5 minutes)
```

**Comprehensive Tests** (run before release):
```bash
pytest -m eol  # End-of-line tests (~20 minutes)
```

### Test Reports

Generate JUnit XML for CI integration:
```bash
pytest --junitxml=test-results.xml -v
```

Generate coverage report:
```bash
pytest --cov=tinymovr --cov-report=html
```

## Best Practices

### Do's

✓ **Always calibrate first** in HITL tests (use `self.try_calibrate()`)
✓ **Use appropriate markers** (@pytest.mark.hitl_default, etc.)
✓ **Test edge cases** (limits, errors, invalid inputs)
✓ **Check for errors** after operations
✓ **Return to IDLE** at end of test
✓ **Use descriptive test names** and docstrings
✓ **Test on multiple board revisions** for firmware changes

### Don'ts

❌ **Don't skip calibration** and expect position control to work
❌ **Don't forget markers** on hardware tests (will break CI)
❌ **Don't leave motor running** after test (always call `tm.controller.idle()`)
❌ **Don't test safety-critical code** without hardware verification
❌ **Don't modify production config** in tests (use test-specific node IDs)
❌ **Don't assume motor type** (check board revision and adjust limits)

## Test Checklist for Pull Requests

Before submitting a PR:

**Code Changes**:
- [ ] Code builds without warnings
- [ ] All existing tests pass
- [ ] New tests added for new functionality
- [ ] Tests cover edge cases and error conditions

**Hardware Changes**:
- [ ] Tested on R5.x board
- [ ] Tested on M5.x board (if applicable)
- [ ] Verified `tm.scheduler.load` < 3000 cycles
- [ ] Monitored for oscillations, instability, overheating
- [ ] No scheduler warnings

**Documentation**:
- [ ] Test docstrings describe what is being tested
- [ ] SAFETY.md updated if adding safety constraints
- [ ] TESTING.md updated if adding new test patterns

## References

- [CONVENTIONS.md](CONVENTIONS.md) - Code style and patterns
- [ARCHITECTURE.md](ARCHITECTURE.md) - System architecture
- [SAFETY.md](SAFETY.md) - Safety-critical constraints
- [CONTRIBUTING.md](CONTRIBUTING.md) - Contribution workflow
- [studio/Python/tests/tm_test_case.py](studio/Python/tests/tm_test_case.py) - Base test class

---

**Document Status**: Living document, updated as testing practices evolve.

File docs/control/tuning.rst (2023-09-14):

.. _Tuning:

**********
PID Tuning
**********

Tuning PID gains can be an iterative process, and it's essential to approach it systematically to achieve the desired performance. Here's a basic guide for tuning the PID gains for your Tinymovr:

Preliminaries:
##############

- Ensure the motor won't cause damage or injury if it starts to oscillate or behave unexpectedly. Fasten the stator assembly to avoid loosening in case of excessive oscillations.
- If the default gains cause oscillations, reduce all gains until the system is stable.

Tuning the Velocity Controller
##############################

Proportional Gain (P)
---------------------

1. Gradually increase the proportional gain until the system starts to oscillate when given a step change in velocity command.
2. Note this gain value down. This is the critical gain.
3. Set the velocity proportional gain to roughly half of the previous value for a balance of performance and stability.

Integral Gain (I)
-----------------

1. With the proportional gain set as above, slowly increase the integral gain.
2. If the motor starts to oscillate, decrease the integral gain slightly until stability is achieved.
3. The role of the integral gain is to eliminate steady-state errors. Ensure that with the selected gain, errors in the steady state (like due to friction or minor disturbances) are reduced.

Tuning the Position Controller
##############################

Proportional Gain (P):
----------------------

1. Start increasing the proportional gain. The system will use the already-tuned velocity controller as an intermediate step.
2. Increase until you notice overshoot in the position response. If overshooting is excessive or oscillations start, reduce the gain slightly until satisfactory performance is achieved without instability.
3. Ideally, the response should be quick to reach the desired position but without excessive oscillations.

Tips and Considerations:
########################

- Always make changes in small increments.
- If the system becomes unstable at any point, revert to previous settings and proceed more cautiously.
- Remember that real-world systems have nonlinearities and disturbances. Your tuning might need tweaking under different conditions or loads.

Final Testing:
##############

Once you believe you've set the gains appropriately:

1. Test across the entire range of operational conditions to ensure stability and performance.
2. Introduce disturbances if possible (like changes in load) to verify robustness.
3. Adjust as necessary based on real-world performance.

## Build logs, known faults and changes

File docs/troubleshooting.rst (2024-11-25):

***************
Troubleshooting
***************

FAQ
***

**Q**: I'm getting "OSError: Could not autodiscover CAN channel" when launching Tinymovr Studio

**A**: This error appear if the CAN adapter is not detected. If using Tinymovr on Windows with a CANtact-compatible CAN Bus adapter, such as CANine, you will need to install an .inf file to enable proper device naming. You can [download the inf file here](https://canable.io/utilities/windows-driver.zip). Extract the archive, right click and select Install.

**Q**: Tinymovr is not detected after launching Tinymovr Studio

**A**: This issue may have several causes, but one of the most common ones is not enabling the termination resistor on the CANine adapter. Please flip the corresponding DIP switch on the CANine and try again, power-cycling the Tinymovr and reconnecting the CANine.

**Q**: I upgraded the firmware and now the board is stuck in DFU mode. Resetting it still gets me to DFU.

**A**: Make sure you have downloaded the **upgrade** variant of the correct binary for your board from the releases page, and flash that.

**Q**: In the Arduino library I'm getting a "Wrong device spec!" error.

**A**: This error appears if the Arduino library is a different version from the Tinymovr firmware. Ensure the Arduino library you downloaded from releases is the same minor version as the firmware you have flashed on your Tinymovr. 

**Q**: How can I use the Tinymovr or Axion R1 actuator with an Arduino? Which CAN library and Arduino hardware to use?

**A**: We've had best results with the Arduino MKR Wifi 1010 and CAN Shield. The Arduino UNO + MCP2515 breakout should also work, but if you are a beginner, try the MKR Wifi 1010.

___

For more answers, please take a look at `Github Discussions <https://github.com/yconst/Tinymovr/discussions>`_ and `Github Issues <https://github.com/yconst/Tinymovr/issues>`_ , and ask any questions there.

You are more than welcome to join the `Tinymovr Discord Server <https://discord.gg/nM7PnXD4>`_ and ask any questions there, or have a chat with us!

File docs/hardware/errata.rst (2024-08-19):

Hardware Errata
###############

.. _alpha-erratum-1:

Tinymovr Alpha CAN Bus Connector
****************************************

The CANine v1 Adapter that came with Tinymovr alpha had the DF-13 pins reversed and as such is not compatible with regular DF-13 cables. Alpha users are advised to use the alternative pin header on the board and the included DF-13 to 2.54mm pin converter cable to communicate with Tinymovr, as shown in the diagram below:

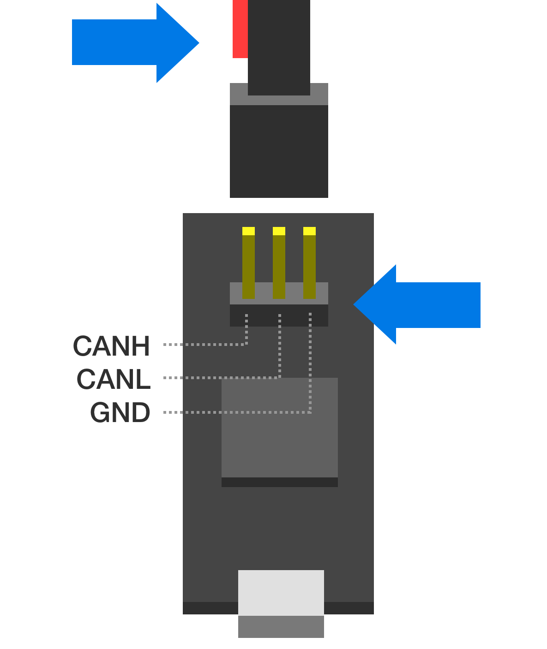
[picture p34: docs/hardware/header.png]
Tinymovr alpha pin header connection


Note above that the red wire should stay disconnected and to the left side of the board as viewed from the USB port side.

.. _alpha-erratum-2:

Tinymovr Alpha USB Micro Connector
******************************************

The USB Micro connector used in the v1 adapter was unfortunately not very robust. In order to ensure that there is a good contact between the board and the USB cable, please ensure the male connector of the cable is firmly seated in the female connector of the board.

In addition, avoid exerting lateral forces to the connector (upwards or downwards) as they place stress on the soldered retaining flaps.

Later adapter revisions (aka CANine) use a USB Type C connector and do not have this issue.

.. _r51-erratum-1:

Tinymovr R5 UART Silkscreen Reversed
************************************

The silkscreen next to the UART port on the rear of Tinymovr R5 has the order of pins reversed. The correct pins are provided in the figure below.

This does not affect R5.2 and above.

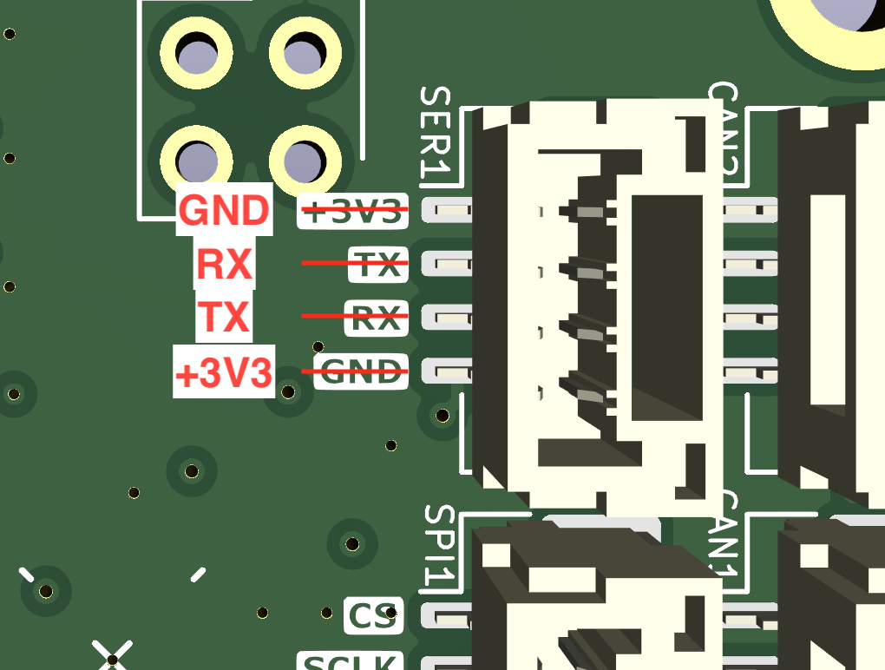
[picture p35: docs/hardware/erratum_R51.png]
Tinymovr R5 reversed silkscreen on UART port


.. _r52-erratum-1:

Tinymovr R5.2 FLEX2 Port as SPI
************************************

Even though Tinymovr R5.2 has the FLEX2 port which can function as SPI, due to a hardware incompatibility this port does not implement SPI correctly. As such, external sensors are only supported on the M5.x series at the moment.

Tinymovr R5.3 and above does not have this issue and supports external SPI sensors normally.

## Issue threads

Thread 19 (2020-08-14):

Save and restore board configuration

yconst, 2020-08-14:
For the most part it is possible to save and restore board configuration by accessing individual endpoints through CAN Bus, without modifying the firmware

yconst, 2020-09-04:
Addressed in #37

Closed 2020-09-04.

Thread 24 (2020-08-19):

Optional flux braking

yconst, 2020-08-19:
This way if enabled the motor will dissipate most of the kinetic energy as heat in the stator windings, similar to a brake resistor.

yconst, 2020-09-07:
Ben Katz wrote about a sensorless temperature estimator here http://build-its-inprogress.blogspot.com/2019/10/motor-temperature-estimation-without.html , this could be used to limit the braking current.

Closed 2022-10-26.

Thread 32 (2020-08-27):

Hardware CAN filtering

yconst, 2020-08-27:
Studio is currently comparing CAN IDs manually, i.e. in the receiver method. Use hardware/kernel filtering instead, which is supported in python-can.

yconst, 2020-08-27:
This won't work because Studio needs to potentially compare multiple filters, one for each Tinymovr instance. Still the code is available at https://github.com/yconst/Tinymovr/tree/attic/studio/refactor-receiver

Closed 2020-08-27.

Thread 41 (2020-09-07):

Expand support to non-serial devices

yconst, 2020-09-07:
Currently the discovery method assumes that a serial device is used. This excludes e.g. socketcan and other devices.

- [ ] Revise discovery method to search for different device types
- [x] Implement and test socketcan

yconst, 2020-09-08:
Socketcan is already supported in fact, using: `tinymovr --iface=socketcan --chan=can0`

yconst, 2021-04-10:
Closing this for now, as all python-can supported interfaces are in fact supported through Tinymovr Studio

Closed 2021-04-10.

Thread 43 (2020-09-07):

Manage idle power consumption

yconst, 2020-09-07:
Currently the PAC experiences a rather large idle power, around 0.8W. There are two possible ways to manage that:

- [x] Use the 10V buck converter instead of the 12V (default) one.
- [x] Use a clock divider to reduce the PWM timer clock frequency.

How effective each of these is remains to be seen in practice..

yconst, 2020-10-16:
Addressed in #62

Closed 2020-10-16.

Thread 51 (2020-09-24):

Refactor control and calibration loops

yconst, 2020-09-24:
- [x] Implement caller function in main loop
- [x] Use __WFI to put MCU to sleep
- [x] Refactor calibration sequence into separate routines

yconst, 2020-11-02:
Resolved in #69

Closed 2020-11-21.

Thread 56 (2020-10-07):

Feedforward current in set_vel_setpoint decoded as int16_t instead of float

yconst, 2020-10-07:
https://github.com/yconst/Tinymovr/blob/2e7d6a76cb8042adb0f294971f5861ebcbf553f9/firmware/src/can/can_endpoints.c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

Should be interpreted as float, users are currently discouraged from using feed-forward current in velocity mode.

yconst, 2020-10-10:
Fixed in #59

Closed 2020-10-10.

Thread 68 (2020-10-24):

Detect erroneous encoder readings

yconst, 2020-10-24:
Disable driver if the values returned by the encoder are outside a threshold. This could be either a hard-coded value compared to |p(t) - p(t-1)|, or a confidence threshold based on sensor noise statistics.

yconst, 2020-12-21:
Resolved in #92

Closed 2020-12-21.

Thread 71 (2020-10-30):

Some UART commands do not trigger response

yconst, 2020-10-30:

yconst, 2020-10-31:
Fixed in #72

Closed 2020-10-31.

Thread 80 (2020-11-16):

Document CANine adapter

yconst, 2020-11-16:
- [x] Connectors on board
- [x] DIP switches function and positions
- [x] Flashing and upgrading firmware

yconst, 2020-11-17:
Resolved in #81

Closed 2020-11-17.

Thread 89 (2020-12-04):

Add hard limits to velocity and current

yconst, 2020-12-04:
Those limits should not be changeable and should be prioritized over user set limits.

Proposed:
Velocity 600000 ticks/s (~4000rpm)
Current 45A

Closed 2020-12-28.

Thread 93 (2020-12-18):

Handle user state input while in calibration

yconst, 2020-12-18:
It is currently possible to switch state through (erroneous or malicious) user input during calibration. While state cannot be switched to closed loop control, as the various components calibration flags are not yet set, it is very well possible to switch to idle. This disables the gate drivers while the calibration is running, producing all sorts of errors and unsafe conditions.

Find a proper way to handle the above.

Closed 2021-02-07.

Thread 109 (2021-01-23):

Eccentricity calibration

yconst, 2021-01-23:
Encoder magnets are imperfectly aligned to the IC which introduces nonlinearities in encoder position reporting. Calibrate these out.

Here's an informative article by Ben Katz: https://build-its-inprogress.blogspot.com/2017/03/encoder-autocalibration-for-brushless.html

First try in [this branch](https://github.com/yconst/Tinymovr/tree/firmware/calibrate_eccentricity) looks quite good.

Closed 2021-02-13.

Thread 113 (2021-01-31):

Rename tinymovr CAN module

yconst, 2021-01-31:
Currently tinymovr.iface.can could potentially conflict with python-can's can module. Ideally both should be renamed to something more descriptive.

yconst, 2021-03-27:
Resolved with #126

Closed 2021-03-27.

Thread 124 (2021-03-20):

Allow position limits on firm ware

ThotAlion, 2021-03-20:
This is a proposition of enhancement in case of joint articulation control (no speed control, no torque control). When the zero is set and the direction is set, the objective is to set limits on the position set-point as safety.

yconst, 2021-03-20:
Sounds good. As a note, this could also work individually, without necessarily setting the direction.

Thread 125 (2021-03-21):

Add homing procedure

lokiledev, 2021-03-21:
Add a procedure for finding the endstop.
This would be a good addition with #114 .

It would work only in position mode, typically for a robot joint control, where there are mechanical endstops.
It is hard to make a generic procedure that works for all sizes of robots, but the algorithm could be something like the following.

* Start with `target position = current position`.
* Create a moving target position with a constant speed, the speed can be the input parameter of the procedure, the sign of the speed target gives also the direction of the motion.
* Monitor measured position, once the position error between target and measurement passes the tolerance, it means the endstop has been reached.
* Set the detected position as the new zero position.

Alternatively if using #124 the new found position could be set as one of the position limits, so that the new zero is the real zero.

yconst, 2021-03-21:
Yep sounds good, thanks.

Not sure if it would be best using delta_pos, I would try also by observing torque (=effort), they are related after all.

loikled, 2021-03-30:
> Not sure if it would be best using delta_pos, I would try also by observing torque (=effort), they are related after all.

Yes that is an option, however I feel that it will be too dependent on the motor and reduction parameters, it's hard to find a generic torque threshold, as for position since the axis is blocked on the endstop, the difference between target and measurement will always increase.

I will implement it externally to do a proof of concept, if that works maybe it's not necessary to implement it in the board, it adds complexity to the firmware.

yconst, 2021-04-02:
> Yes that is an option, however I feel that it will be too dependent on the motor and reduction parameters, it's hard to find a generic torque threshold, as for position since the axis is blocked on the endstop, the difference between target and measurement will always increase.

You have a point. However, I would argue that similar limitations hold true for position-based endstop detection. Namely, what would be the Δpos (setpoint-estimate) that would be acceptable? This depends on the reduction of a system of course. In addition, there is a danger that if the current limit is not properly set, advancing the position beyond the endstop could cause mechanical damage.

In the end, it is a matter of what the user would prefer to set before the process. On one hand, position-based detection should have a current limit and Δpos_max set by the user. On the other hand, torque-based would need a max torque (=current limit) and eventually a min time period that the torque is applied, beyond which the endstop would be confirmed.

Food for thought.

> I will implement it externally to do a proof of concept, if that works maybe it's not necessary to implement it in the board, it adds complexity to the firmware for a specific mode only (position mode).

Looking forward to your results when you manage to do so!

ThotAlion, 2021-04-03:
Another idea for homing procedure shall be to control the motor in speed (low speed) and observe when the encoder really stops (maybe with a small shock profile). The algo can be set_velocity_setpoint -> if abs(encoder velocity)<threshold->take the encoder position as a mechanical stop. This may be less dependent on a threshold dependent on the robot.
Whatever, the homing procedure shall be done in ideal conditions (no mechanical disturbance, no gravity torque)

lokiledev, 2021-04-03:
I agree, the catch is that however the algorithm it's hard to make it generic /compatible with all scenarios and there will need to be some parameters. It's probably better to let the external controller do this stuff and just provide a command to set the zero and or even only position limits.

lokiledev, 2021-04-03:
Another idea could be to have an external index signal like the switches in a 3d printer that are used for homing. Maybe on next board revision.

Closed 2023-05-14.

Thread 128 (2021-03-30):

Set motor parameters for high current motors

yconst, 2021-03-30:
Currently only available in Gimbal mode, should be available in high-current motor mode as well.

yconst, 2021-03-30:
This is already implemented, false alarm :)

Closed 2021-03-30.

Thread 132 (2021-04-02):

Add gimbal motor unit tests

yconst, 2021-04-02:
Such unit tests can be performed with a high-current motor, by specifying correct calibration current values, and motor constants R and L.

yconst, 2021-04-04:
Resolved in #134

Closed 2021-04-04.

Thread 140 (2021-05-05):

Filter VBus readings

yconst, 2021-05-05:
Reduce the VBus bandwidth and increase accuracy.

yconst, 2021-09-24:
Fixed by #155

Closed 2021-09-24.

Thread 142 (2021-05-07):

One shot command and feedback for high rate control

ThotAlion, 2021-05-07:
For high rate motor control at server level, it should be interesting to have a function in API which sends goal position by CAN and recup the feedbacks (position, speed, temperature, etc).
In "one shot" of CAN, you can give an order and get feedback.

Kind of :

...
[pos,speed,iq,temp] = tm.send_get_position(position,speed_feed_forward,current_feed_forward)
...

yconst, 2021-05-10:
Sounds good. The cleanest way this could be implemented is to 'overload' the read endpoints to accept setting values, by clearing the RTR bit. Then, the 'request' frame would also set the values, and Tinymovr would respond with a response frame as usual.
This could be implemented for a handful of real-time endpoints.
The data returned would be the same as the ones supported by the endpoint.

yconst, 2021-09-24:
Fixed by #155

Closed 2021-09-24.

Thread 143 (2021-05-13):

Firmware flasher for Tinymovr Studio

yconst, 2021-05-13:
Currently we use ActiveSemi's own application for flashing firmware. This could be made easier by using an automatic flasher embedded in the Python REPL or as a command line param.

yconst, 2023-09-05:
Fixed in #279

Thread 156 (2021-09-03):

16bits for motor_inductance is too small for some small gimbal motors

DarrenLevine, 2021-09-03:
I'm using a small gimbal motor (T-Motor GB36-1) with tinymovr, and according to a LCR meter (assuming I'm measuring it correctly...) the motor has a high inductance of 158,300 microhenries. The tmx.set_motor_config interface only allows 16bit values for motor_inductance in microhenries, so it can't represent a large enough value for this specific motor. Jamming in the highest inductance I can and then manual tuning of the gains lets me get around this and control the motor in position-control mode, though it's perhaps more manual than would be ideal.

yconst, 2021-09-03:
Thanks for this issue. Indeed this is a limitation, that came due to the limited size of the CAN frame. We're working on a large refactoring of the comms but it's early for that and it will take some time. In the meantime, we could refactor the endpoints to use two separate ones, one for instance for configuring R and L and one for pole pairs, flags and calibration current.

Closed 2022-02-07.

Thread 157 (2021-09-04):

low current threshold feature for lower power/torque operations

DarrenLevine, 2021-09-04:
When first powering on tinymovr, I think the gate driver starts in a disabled mode, and so the attached motor's resistance to being turned is at its minimum, and its current draw is also very very small. However, by just enabling current control mode, even if the commanded current is still at zero, the gate driver is enabled, which increases idle current draw (doubles it in my experiments), and increases the motor's resistance to turning. If attempting torque control, and trying to get as close to zero torque as possible, the motor's friction may in some motors have a smaller torque effect than an enabled gate driver (commanded to some current below a user provided threshold), which makes it more desirable from a power draw and control dynamics standpoint to just disable the gate driver under a certain current threshold. Especially if the motor has a lot of extra friction due to a gearbox.

It would be a cool feature to let the user specify a current threshold for disabling the gate driver, to unlock that extra low-torque control, and get a small power savings to boost when idling for long periods of time.

Or instead of having the user set this threshold manually, during calibration, you might actually be able to automatically determine this low-current threshold by slowly ramping the current down while the motor is actively turning (to measure dynamic friction), until the current is low enough that it cannot overcome that particular motor's friction and so the motor stops moving at a specific low current level. I assume that dynamic friction will be lower than static friction, so I wouldn't suggest measuring it by increasing the current of a stopped motor until it starts turning, since that value would probably give you too large of a current threshold (though I'm speculating on that one). Then, if you take that lowest measured current value and divide it by 2, and use it as your threshold value for disabling the gate driver, you'll essentially end up taking the user's commanded current control value and rounding to the closest possible state for that particular motor, giving them a tiny bit of extra control authority and power savings.

When I've messed with the STSPIN32 MCU in the past, I remember it has a standby mode you could quickly enter-into / exit-out-of to accomplish this sort of feature, but fair warning, I don't know if the same is feasible (and safe) with the PAC5527.

Very cool product by the way, I'm very much enjoying using my Tinymovr boards so far.

yconst, 2021-09-05:
Thanks for this issue and the feedback!

As a first comment, I think the issue you are describing might be related to the other issue you raised, #156 . Let me explain.

At current control mode, the FOC loop still runs in the background. This means that for a well-tuned current controller, the d and q components should be close to zero (as the commanded q-current is zero). Therefore, the motor should exhibit the same characteristics as if the phases were disconnected when the inverter is off.

Now, if the current controller gains are tuned for a motor with different RL characteristics, this could also affect the current regulation performance, and introduce errors even if the commanded q component is zero. The resistance that you mention could thus be related to improper current controller tuning.

I have tested current control and it does not seem to impede motor movement to a noticeable degree. Granted, my test was in a high-current motor, with much lower RL than yours, so any effect could be much less pronounced in my case.

Nonetheless, your suggestion is interesting and I'm going to leave it open for consideration.

Thanks!

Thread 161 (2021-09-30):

set Tinymovr CAN bus speed mandatory ?

ThotAlion, 2021-09-30:
When setting the CAN ID to a Tinymovr, is it mandatory to set the bus speed ? or is there a default value ?

Thank you.

ThotAlion, 2021-09-30:
The version used is 0.8.10

yconst, 2021-10-04:
There is a default value of 0, which is ignored by the firmware. The default values are [described in the endpoints map](https://github.com/tinymovr/Tinymovr/blob/master/studio/Python/tinymovr/iface/can_bus/endpoints.py)

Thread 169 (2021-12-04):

Fix a few things in docs

yconst, 2021-12-04:
- [x] Fix pinout of UART port to align with silkscreen
- [x] Move warning in UART interface section

yconst, 2021-12-05:
Fixed in #168

Closed 2021-12-05.

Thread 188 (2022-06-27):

Quadrature encoder support

gsion1, 2022-06-27:
Hi,
Do you plan to add quadrature encoder support with A and B channel, plus index ? It seems that there is enough pins in the new tinymovr R5. It's sometimes hard and not reliable to use the board's encoder, especially in hard environnement or with outrunners motors (bracket can vibrate, bend etc)
The big issue with that is that the motor doesn't exactly know where is it when it starts and the motor may jerk, but maybe that's okay in some applications ?

Thanks a lot, have a nice day !

gsion1, 2022-06-28:
Hi,
Thanks a lot for your answer
It means that you plan to implement external encoder support ? I'm not able to see the roadmap, is it public ?
Thank a lot !

yconst, 2022-06-28:
Yes we do have Hall effect sensor support in place, although we're still working on documentation. Next one is SPI sensor support.

There is no public roadmap atm.

gsion1, 2022-06-29:
Thanks for your help ! Have a nice day

Closed 2022-06-29.

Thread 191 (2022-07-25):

CAN Watchdog option

amcunio, 2022-07-25:
We are wanting some additional functionality for the firmware to have a watchdog that halts the motor if it stops receiving CAN messages on the bus.

If we were to implement this, would this be likely to be merged in. Additionally, are there any design requirements that you have for the overall repository that would help this in getting passed through.

yconst, 2022-07-25:
Thank you for the comment. Yes, we would like to merge as this is a desired functionality.

We run a firmware build and cppcheck for each board revision during CI. In C we loosely follow the [Google Style guide](https://github.com/google/styleguide). And in Python we try to use [Black](https://github.com/psf/black).

That's all. Just open a pull request when you are ready.

Thanks.

Closed 2022-08-17.

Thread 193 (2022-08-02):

Voltage increase stops motor functionality

amcunio, 2022-08-02:
We have been trying to increase the voltage slightly when running the motor controller. Pushing it from 32V->33V causes the motor to stop functioning. If it is underway this makes it stop and if attempting to calibrate this causes the resistance to be out of range.

Looking at the [resistance calibration sequence](https://github.com/tinymovr/Tinymovr/blob/9462d55c24cedc9aebed433fbcad0d7c9db48fa6/firmware/src/motor/calibration.c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) that fails using a debugger, observing the variables, the resistance @32V is R=~0.5 and when increasing by 1V, @34V R=~20. This is a sharp increase and I am not sure why this seems to be occurring.

Is anyone familiar with what in the firmware may be causing this to occur?

yconst, 2022-08-13:
Hi, I've tried this using a tinymovr R5, and it seems to be working without any issues, changing the voltage while in closed loop control does not affect functionality. I'm wondering if there could be some voltage transient affecting your case.

amcunio, 2022-08-22:
Thanks for looking into this, looking further it appears a voltage issue on our side.

Closed 2022-08-22.

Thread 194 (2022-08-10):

Duty Cycle Mode

eufrizz, 2022-08-10:
Hi,
I am interested in being able to switch the Tinymovr to a "duty cycle" control mode, effectively open-loop, sensorless speed control. I would be interested in your thoughts on how this could best be implemented and integrated into the Tinymovr firmware, and would love to contribute it to the project if you are interested!

yconst, 2022-08-13:
Thanks for the contribution. This could be implemented as a new control mode that essentially keeps a position reference local to the control loop. Commutation then maintains current to the corresponding angle to provide the holding torque. The windings are energized all the time. There is no current control in this mode, but a velocity and position control could be implemented.

This still needs a bit of thought on how to combine with the various encoder types Tinymovr will soon support.

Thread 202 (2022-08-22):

Current limit feedback

amcunio, 2022-08-22:
Hi,
We are wanting a way to get feedback back from the motor based on if the current limit is met. The motor will clamp the current setpoint being sent to the motor based on a settable current limit. As it stands an error is returned if the current level is too high (1.5 * this limit). We, however, would like some feedback on whether the limit has been reached and clamping occurs.

Detecting this shouldn't be hard, however we were wanting some feedback on what your preferred method of providing information to the user would be. Some possibilities we have are:
 - giving feedback in the get_vel_setpoint function if the velocity setpoint is causing the current limit to be exceeded
 - having a separate warnings channel (as currently only errors are returned and warnings can also be provided to the user)

yconst, 2022-08-23:
This issue contains very good ideas that I'd like to implement. The warnings channel, especially, is something that we've been considering ourselves. We are currently working on a [rewrite of the comms layer](https://github.com/tinymovr/Tinymovr/pull/201), which will allow gaining better insight in the state of Tinymovr. An endpoint for issuing warnings could be added there. The way we currently work with errors is that each submodule (e.g. encoder, controller, adc) has a bitmask for errors that corresponds to an endpoint. Similarly a bitmask for warnings could be implemented.

yconst, 2022-10-06:
We now have initial warnings endpoint support in the develop branch

Closed 2022-10-06.

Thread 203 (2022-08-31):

Hall Mode

eufrizz, 2022-08-31:
I've been working on getting hall sensor feedback working (there were multiple bugs with selecting the different encoder type and calibrating it - the code seems pretty much untested with this mode). I have gotten it to a stage where it calibrates reliably and gets good feedback, so I can see the hall sector is picked up on and the position estimate increases/decreases as expected when you spin the motor by hand.
Unfortunately however, the control loop seems unable to spin the actual motor (in velocity or current control). It will ramp up the current and make the motor stiff but it won't spin. Any ideas why? Maybe it needs to be adapted to the vastly lower resolution (6 ticks vs thousands per revolution)? If you want to test it yourself, the working software is under the fixHallMode branch in my fork.
Thanks!

yconst, 2022-08-31:
Hi Eugene,

Thanks for raising these issues. Admittedly, the sector_map endpoint was never used much, but the rest of the encoder configuration and calibration process has been tested extensively before release. Nonetheless, I looked at the documentation following the issue you raised, and noticed some omissions. These to be addressed in a separate issue.

Now to your problem. Most probably the gains need updating, like you correctly mentioned this is due to the change in mechanical resolution. I will update the docs with indicative values for the motor we tested on (it is a hoverboard motor), and add the necessary steps.

yconst, 2022-09-02:
#204 improved documentation regarding hall effect sensor, further information to be added.

yconst, 2022-09-07:
Work on docs is complete on this one. If you plan to create a PR we'll gladly merge it.

eufrizz, 2022-09-14:
Hi Yannis, thanks for updating the documentation, it was helpful! I've been testing hall mode on a MA330 encoder, which can simulate UVW output. I've added some convenience functions for reading/writing to the encoder registers (which are not actually used in the PR but could be useful for others in future), a new calibration function for the hall encoders, and tweaked some things in the CAN endpoints.
https://github.com/tinymovr/Tinymovr/pull/205

Closed 2022-10-02.

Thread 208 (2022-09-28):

Measure DC current

eufrizz, 2022-09-28:
Hi Yannis,

If I wanted to measure the instantaneous DC current being used by the motor (as a power meter might read), how could I do this? Would it just be a matter of adding the currents on each phase or is there more to it? I'm a little confused by what's going on in the ADC_UpdateMeasurements function and can't seem to find any info on current readings in the documentation.

Thanks!

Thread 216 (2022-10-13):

Doesn't run with compiler optimisations

eufrizz, 2022-10-13:
1. I've noticed when flashing the release version of the code, the ESC can't spin the motor. I've tried -O1, -O2 and -O3, and only O1 works. Usage of -O3 is generally discouraged, but it would be nice to run at -O2 for full optimisation and less likelihood of reentering the control block etc. Do you have any idea why -O2 might not be working? I am able to communicate via CAN but can't get it to calibrate or the motor to spin. I'm flashing via J-Link.

2. Additionally, for debug, I've found (sorry if you already knew this but I thought I'd record them anyway):
- Using -g2 is much more useful for debugging via the J-Link, and actually shows the local variables whereas -g1 does not.
- The debug optimisation flag -Og doesn't seem to make a difference compared to the -O1 we already use for debug.
- No optimisation (-O0) results in a compiler error as the resulting binary is probably too large to fit on memory.
As a result I think it would be worthwhile changing the debug flag to -g2.

3. Finally, with the VSCode workflow, I noticed that with my PR (https://github.com/tinymovr/Tinymovr/pull/207) that it wasn't actually rebuilding when switching to release, so I was unknowingly flashing in debug the whole time (which is why it worked). I think this is what you mentioned [here](https://github.com/tinymovr/Tinymovr/issues/209).
When I make clean and then build and flash release, the issue in 1 occurs. This is a bit confusing, so I propose we change the preLaunchTasks to be "Clean and Build Project (<Release/Debug>)" to force it to rebuild with the expected version (rebuilding doesn't take long anyway). What do you think?

yconst, 2022-10-13:
Hi @eufrizz ,

1. Do you get an error? Does calibration run? Which gcc version are you using? Have you tried the prebuilt release binaries? This is odd, as we flash release versions on every board we distribute and then test it; in this sense the release build is always verified.
2. Cool, thanks for sharing your findings! -g2 was the original flag, but we found that it generates linker errors with arm gcc12. We found that some loops in the nvm_save function are substituted with calls to memcpy; The function itself needs to be in RAM but memcpy resides in flash, so the linker fails. Thus we temporarily reverted to -g1 until this is further investigated.
3. This is a known issue, we revised the launch configurations in  #213

Note that we are basing new feature PRs off the develop branch (which includes the new Avlos-based comms stack), the master branch atm only accepts hotfixes.

yconst, 2022-10-13:
Also, is there a specific reason for suggesting avoiding -O3 ? I would love to hear more.

eufrizz, 2022-10-14:
1. No errors, calibration does not run - it just stays in calibration state forever.
Didn't manage to flash the prebuilt binary via VSCode but with did it with JLinkExe at address 0x1000 and it worked.
My compiler version is `arm-none-eabi-gcc (15:6.3.1+svn253039-1build1) 6.3.1 20170620`. I suspect it is a compiler version problem. Can't seem to find which compiler version you use - would be good to know.
2. Ah ok good to know. We're definitely using different compilers then.
3. Didn't see that! Thanks for pointing me to it.

As for -O3, I am no expert, but from what I can see it comes with a few caveats which can actually make the program slower and the binary larger. Here is some [discussion](https://stackoverflow.com/questions/11546075/is-optimisation-level-o3-dangerous-in-g). Here is the [arm gcc documentation](https://developer.arm.com/documentation/den0013/d/Optimizing-Code-to-Run-on-ARM-Processors/Compiler-optimizations/armcc-optimization-options), which states that 02 is the default. It is definitely not a clear cut case and requires some profiling/testing/digging in which is probably not worth it for this use case but is interesting!

yconst, 2022-10-18:
As a side note, there is a file called "z_testbed_fw_r5" in each release, this is a release binary that includes the bootloader, which we use for flashing and testing all R5 boards. You can try flashing this, it should work with VSCode. But smart move flashing the upgrade binary with JLink!

yconst, 2022-10-18:
In addition, I think that the issues you linked mostly refer to Cortex-A or desktop class machines that have cache, and where some features of -O3 would lead to more frequent cache invalidations, and as such slow down execution. But as you mentioned, more profiling would give a more solid answer!

yconst, 2022-10-30:
I opened #222 after doing some research re. the `-g2` flag. Did you manage to address the build issue?

eufrizz, 2022-10-31:
Great! Didn't end up solving the issue, just sticking to compiling in -O1. Which compiler version are you using?

yconst, 2022-11-02:
I've used mainly 9-2019-q4-major in the past, but now I'm using the latest here: https://developer.arm.com/downloads/-/arm-gnu-toolchain-downloads

yconst, 2022-11-24:
I am going to close this for now, and keep #222  for further investigation in the use of debug flags. I feel that the compiler optimisation issue has been resolved and was due to compiler version? If not, feel free to reopen. Thanks again!

eufrizz, 2024-03-01:
@yconst after coming back to this after a long time, I've realised it was due to a firmware bug. In scheduler.c, the `state` variable is not marked as volatile even though it is altered in interrupts, thus in optimisations higher than -O1 cause the WaitForControlLoopInterrupt function to break.
Confirmed that this fixes my problem on a test motor.
PR submitted here: https://github.com/tinymovr/Tinymovr/pull/327

Closed 2022-11-24.

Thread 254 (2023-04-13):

Emergency stop?

ator1811, 2023-04-13:
Is there an Emergency stop function available? I don't see it in the API reference.

Maybe it is not possible with the R5 board, because a input pin for the button is needed, but maybe a API-command is possible (to interrupt a movement).

yconst, 2023-04-18:
You can set `tmx.controller.state = 0` to immediately disable the inverter

yconst, 2024-05-08:
closing this due to inactivity

Closed 2024-05-08.

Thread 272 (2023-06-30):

Revise min undervoltage conditions

yconst, 2023-06-30:

yconst, 2023-09-21:
The value of 10.4V in the last firmware is a limit that guarantees 10V for low-side gate driving.

Closed 2023-09-21.

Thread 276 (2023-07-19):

Studio does not start

beesjot, 2023-07-19:
Hello

I've successfuly installed tinymovr[GUI] (by use command pip3 install "Tinymover[GUI]") but when I try to start Tinymovr, I can see next messages:

C:\Users\beesj>tinymovr
Traceback (most recent call last):
  File "C:\Users\beesj\AppData\Local\Programs\Python\Python311\Lib\site-packages\tinymovr\config\config.py", line 55, in get_bus_config
    return configs[0]
           ~~~~~~~^^^
IndexError: list index out of range

The above exception was the direct cause of the following exception:

Traceback (most recent call last):
  File "<frozen runpy>", line 198, in _run_module_as_main
  File "<frozen runpy>", line 88, in _run_code
  File "C:\Users\beesj\AppData\Local\Programs\Python\Python311\Scripts\tinymovr.exe\__main__.py", line 7, in <module>
  File "C:\Users\beesj\AppData\Local\Programs\Python\Python311\Lib\site-packages\tinymovr\gui\gui.py", line 48, in spawn
    w = MainWindow(app, arguments)
        ^^^^^^^^^^^^^^^^^^^^^^^^^^
  File "C:\Users\beesj\AppData\Local\Programs\Python\Python311\Lib\site-packages\tinymovr\gui\window.py", line 139, in __init__
    params = get_bus_config(buses)
             ^^^^^^^^^^^^^^^^^^^^^
  File "C:\Users\beesj\AppData\Local\Programs\Python\Python311\Lib\site-packages\tinymovr\config\config.py", line 57, in get_bus_config
    raise can.CanInitializationError("No active interface found") from exc
can.exceptions.CanInitializationError: No active interface found

Can You help me in this problem?

System is Win10, Python v3.11.4. Tinymovr rev5.2 is conneceted two ways to PC: via Serial port, and via USB-CAN-A (Waveshare). Each interface is operating, but it is to little to change configuration of Tinymovr. My target is in control device via Serial port, and use internal motor Hall sensors.

Regards
beesjot

yconst, 2023-07-20:
Hi @beesjot !

This error means that Tinymovr Studio is unable to detect a CAN bus interface. Upon startup, Studio tries to auto-detect a limited number of interface types, namely slcan and canine. For any other type, it needs to be specified as a command line argument (the bustype parameter), using the python-can compatible interface name.

For instance:

    tinymovr --bus=socketcan

So you will need to find the python-can compatible interface name for your adapter first. Once you do that, you can pass it as an argument. If it is still not detected, it means that the python-can driver does not support channel auto-detection, and you will need to supply that as well, for instance:

    tinymovr --bus=slcan --chan=/dev/ttyACM0

your chan parameter depends both on the OS as well as the device itself. For instance, in Windows, it is common to have a COM port as a channel:

    tinymovr --bus=slcan --chan=COMXX

I hope this helps. I am converting this to a discussion as it is not an issue of studio. Please feel free to continue the discussion here.

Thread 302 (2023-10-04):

R5.1 Hall sensor input maximum specification

pipipipi2002, 2023-10-04:
May I know what is the maximum voltage each of the hall sensor can take. I tried searching for schematics in the github to check but failed to do so.

My motor takes in 3.5V-24V for its hall sensor and im thinking of supplying the hall sensor to the same voltage the motor is running on (12V nominal). I wanted to make sure that this is safe for the onboard hall sensor input.

yconst, 2023-10-04:
TL;DR: You should be ok, but 12V is not officially supported. The officially supported voltages for the hall sensor inputs are 3.3V and 5V.

Tinymovr interfaces to the hall sensor via an RC filter with in line 10k resistors. According to the [PAC5527 datasheet](https://www.qorvo.com/products/p/PAC5527#documents) (14.3.2 GPIO Current Injection), the device can tolerate a small amount of injected current for all IO pins, when the voltage is greater than 3.3V. This is stipulated as max 25mA per input and 50mA total. So considering the 3 hall inputs, we can deduct a max injection current of 16mA. 12V over 10k will give a bit more than 1mA, so you should be ok. However we have not attempted a 12V input, and we do not officially support this.

yconst, 2023-10-04:
Converting this to a discussion

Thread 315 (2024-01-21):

Motor configurations being re written during calibration

norsechurros, 2024-01-21:
I have these maxon motors that i am trying to configure with the tinymovr R5.1 , but the values get rewritten during call
bration. I have attached the datasheet with the highlighted values. I read a similar discussion with regards to a gimbal motor, but my motor is a high current motor that i intend to use on a grounded bot.

[EN-21-306.pdf](https://github.com/tinymovr/Tinymovr/files/14000425/EN-21-306.pdf)

The phase resistance error is thrown as a result of which the hall sensors onboard the motor are not being calibrated. I have tried applying a bunch of different values for the phase resistances and inductances as well as the calibration current ,none of which seem to work. However, whenever i do run the calibration command the motor seems to move and draw a little bit of current ending with a beep sound, but the tinymovr goes into an error state(errors: flags.PHASE_RESISTANCE_OUT_OF_RANGE
).
How do i go about fixing this?

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

yconst, 2024-01-21:
A resistance of 0.44Ohms should be accepted by Rx.x firmware, only M5.x firmware rejects resistances lower than 1.0Ohms. Can you post your `tm1. hw_revision` output?

norsechurros, 2024-01-23:
yes sure

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

yconst, 2024-01-23:
Ok so this is an older fw version where the hardware revision attribute was not supported. I'd suggest upgrading to the latest firmware, the instructions can be found here: https://tinymovr.readthedocs.io/en/latest/upgrade/upgrade.html#upgrade-using-activeflashlight-and-uart

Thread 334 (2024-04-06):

TinyMovr R5.2 drawing excessive current during change in modes

norsechurros, 2024-04-06:
These are my configs for a out of the box tinymovr:

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

When i now try setting the tm in velocity mode, calibration or position mode , it draws a very high current spike , and then doesnt end up changing its mode. This particular tinymovr was working for sometime under similar params before as well, until once when it kept drawing a lot of current and ended up burning a really costly motor. At the instance it was powered by a 6s 24V battery through a PDB. Now im trying to test it using a dc regulated power supply which limits current if it exceeds the limit. Why is this happening and whats the fix for it?

The specs are:
Tinymovr R5.2 with out of the box firmware and studio 1.6.5
Maxon Motors EN-21-306
params are stated in the datasheet have been put in as configs here

I feel theres an internal problem with the tm in which case i want to first rule out other possibilities and then look for replacement.

yconst, 2024-04-07:
I'm sorry that your motor got damaged.

To be honest, I'm not sure what could cause this. Was it drawing current continuously when the damage happened? Or was it a current spike?

From your settings, the only thing I can notice is the very high encoder bandwidth of 1500 Hz. For a hall sensored motor, with a low tick resolution, this should be way lower, usually less than 100 hz. Combined with the high gains, this could be a cause for current spikes.

I'm leaving this here in case additional information comes up.

norsechurros, 2024-04-08:
The same bandwidth I had applied to all tinymovrs and motors i have worked with , and still do. Such a problem hadnt come up before, and still doesnt. I changed the bandwidth to a lower one and then tried callibrating it as well as trying to put it in position and velocity mode, all of which results in the same high spike in current draw.

Its an internal problem of this tm.

yconst, 2024-04-10:
Got it. Did not understand that this concerned only a single unit. As this is the case, I'm moving this to the discussions.

I do not have an answer as to why this issue started appearing. If I would hazard a guess, could be either damage to the gate driver, leaving the mosfet on, or an issue with the ADC reporting incorrect current values, thus allowing the current to exceed the regulated value. But these are just hand waving.

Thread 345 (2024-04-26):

CAN timing issue

maxikrie, 2024-04-26:
Hi,

I am facing an issue where two out of three boards (pixhawk-6c-mini) have an issue receiving data from the tinymovr M5 over CAN interface. I have analyzed the signals and it seems to me that on one hand the edges of the response are not very sharp and also the signal seems to drift, potentially causing the issue?

In any case with all boards the sending part seems to be fine and the tinymovr reacts on the incoming date. I have attached to images of the CANL part of the signal where in the second images the white dots and red crosses show where signal is measured to be high or low. It looks like that it is actually changing in this exact moment.

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

Thanks for your help!

yconst, 2024-04-29:
It seems that the timing issue is due to the internal oscillator drift. This is a known issue, and we are investigating whether to have an external crystal oscillator in upcoming hardware versions.

Nonetheless, it seems that the pixhawk might have different CAN Bus settings to CANine (which, as you mentioned seems to work).
It could be worth, if possible, to reconfigure the pixhawk can settings to resemble the ones of CANine:
https://github.com/tinymovr/CANine/blob/67da4a52d44cdf5b18b52eae8d0f14d3b56ca3d4/Core/Src/can.c#L71

The edges appear within acceptable limits.

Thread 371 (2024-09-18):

Unable to use CLI/python api to set external encoder

omelia-iliffe, 2024-09-18:
Hi,
I'm trying to get my TinyMovr M5.1 setup with an external encoder (AS5047) but i'm running into serveral issues.

I first installed the studio using python3.12. The studio opens but when I go to select the encoder only Internal and Hal are presented as options.
I then tried following the Example given in the docs to [External AS5047 Sensors](https://tinymovr.readthedocs.io/en/latest/sensors/sensors.html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) which I assumed was instructing me to use the python api.
I copied the example code from the [Integrating page](https://tinymovr.readthedocs.io/en/latest/protocol/integrating.html)
```
import can
from tinymovr.bus_router import init_router
from tinymovr.config import get_bus_config, create_device

params = get_bus_config(["canine", "slcan_disco"], bitrate=1000000)
init_router(can.Bus, params)
tm = create_device(node_id=1)

tm.controller.calibrate()
```
This code fails immediatly as the init_router function requires a logger parameter. After searching for ages to find out what that parameter should be (Hint it should be pythons built in logger initialized with the `configure_logging` function) I then tried to use the code from the AS5047 example to setup the external encoder and calibrate.
```
tm.sensors.setup.external_spi.type = tm.sensors.setup.external_spi.type.AS5047
tm.sensors.select.commutation_sensor.connection = tm.sensors.select.commutation_sensor.connection.EXTERNAL_SPI
tm.sensors.select.position_sensor.connection = tm.sensors.select.position_sensor.connection.EXTERNAL_SPI
tm.calibrate()
```
But that doesn't work either.
```
Traceback (most recent call last):
  File "c:\Users\Omelia\repos\tinymovr\calibrate.py", line 12, in <module>
    tmx.sensors.setup.external_spi.type = tmx.sensors.setup.external_spi.type.AS5047
                                          ^^^^^^^^^^^
  File "C:\Users\Omelia\AppData\Local\Packages\PythonSoftwareFoundation.Python.3.12_qbz5n2kfra8p0\LocalCache\local-packages\Python312\site-packages\avlos\definitions\remote_node.py", line 48, in __getattr__
    raise AttributeError(__name)
AttributeError: sensors
```

I then realised their was the tinymovr_cli that I hadn't tried but that wasn't working for me either.
It finds my tinymovr (tm1) but everything I type results in errors
```
In [1]: tm1

File ~\AppData\Local\Packages\PythonSoftwareFoundation.Python.3.12_qbz5n2kfra8p0\LocalCache\local-packages\Python312\site-packages\avlos\definitions\remote_attribute.py:62, in RemoteAttribute.str_dump(self)
     61 def str_dump(self):
---> 62     return "{0} [{1}]: {2:.6g}".format(
     63         self.name,
     64         self.dtype.nickname,
     65         self.get_value(),
     66     )

ValueError: Unknown format code 'g' for object of type 'str'
```

```
In[2]: tmx.sensors.setup.external_spi.type = tmx.sensors.setup.external_spi.type.AS5047
File ~\AppData\Local\Packages\PythonSoftwareFoundation.Python.3.12_qbz5n2kfra8p0\LocalCache\local-packages\Python312\site-packages\avlos\definitions\remote_node.py:48, in RemoteNode.__getattr__(self, _RemoteNode__name)
     46         return attr
     47 except KeyError:
---> 48     raise AttributeError(__name)

AttributeError: sensors
```

I also tried with python3.10 on a linux machine to see if it was python3.12/windows 11 that was causing the problems but no to avail.

Any help would be appreciated.

yconst, 2024-12-03:
Hi,

Apologies for the late reply. I'm looking into this and will reply to you very soon.

yconst, 2024-12-08:
We fixed the logger and object print issues in the latest Tinymovr Studio release (2.3.2):
https://pypi.org/project/tinymovr/

please use `pip install --upgrade tinymovr`

We also improved the documentation to refer to `tm1` insteda of `tmx` with a note for applying to other nodes in the bus.

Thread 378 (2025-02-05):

NO response by tinymovr studio on operating a bldc motor, tinymovr R5.3 with canine v1.4 adapter

TayyabAsim047, 2025-02-05:
Tinymovr Version: R5.3
BLDC Motor Model: [JD-power DCH-6829F flat dc hollow shaft brushless motor with switch hall sensor]
Bus Interface: [SLCAN]
Tinymovr Studio Version: [2.3.2]

Issue Description:
I am using a Tinymovr R5.3 board to control a BLDC motor via Tinymovr Studio, but I am not getting any response when sending commands. The board is detected, and communication over [CAN/SLCAN] is established successfully. However, when issuing movement commands, the motor does not move, and there is no feedback in Tinymovr Studio.

Expected Behavior:
The BLDC motor should rotate based on the commanded setpoint, and Tinymovr Studio should provide real-time feedback.

Observed Behavior:
No motor movement
No output or error messages in Tinymovr Studio
Board appears connected but does not execute commands

Troubleshooting Attempts:
Verified power and wiring connections
Confirmed motor parameters (resistance=1.6ohm, inductance=2.11mH, pole pairs=11)
Tested different bus interfaces (tinymovr_cli shows device, but no control)
Reinstalled Tinymovr Studio and drivers

Any guidance on debugging or further troubleshooting would be greatly appreciated. Thanks!

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

yconst, 2025-02-05:
Please post the motor parameters including errors.

Please note that Tinymovr R5.3 does not support motors with internal resistance > 1Ohm

yconst, 2025-02-05:
Please note that Tinymovr R5.3 does not support motors with internal resistance > 1Ohm

yconst, 2025-02-05:
Converting this to a discussion

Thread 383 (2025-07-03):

UNDERVOLTAGE issue

Tunauner, 2025-07-03:
When I power the device with the power supply, I get an UNDERVOLTAGE error when I first open the gui. The error is fixed when I play with the cables a little, but when it is first turned on, I get an UNDERVOLTAGE error even though it reads the volts correctly.

Closed 2025-07-04.

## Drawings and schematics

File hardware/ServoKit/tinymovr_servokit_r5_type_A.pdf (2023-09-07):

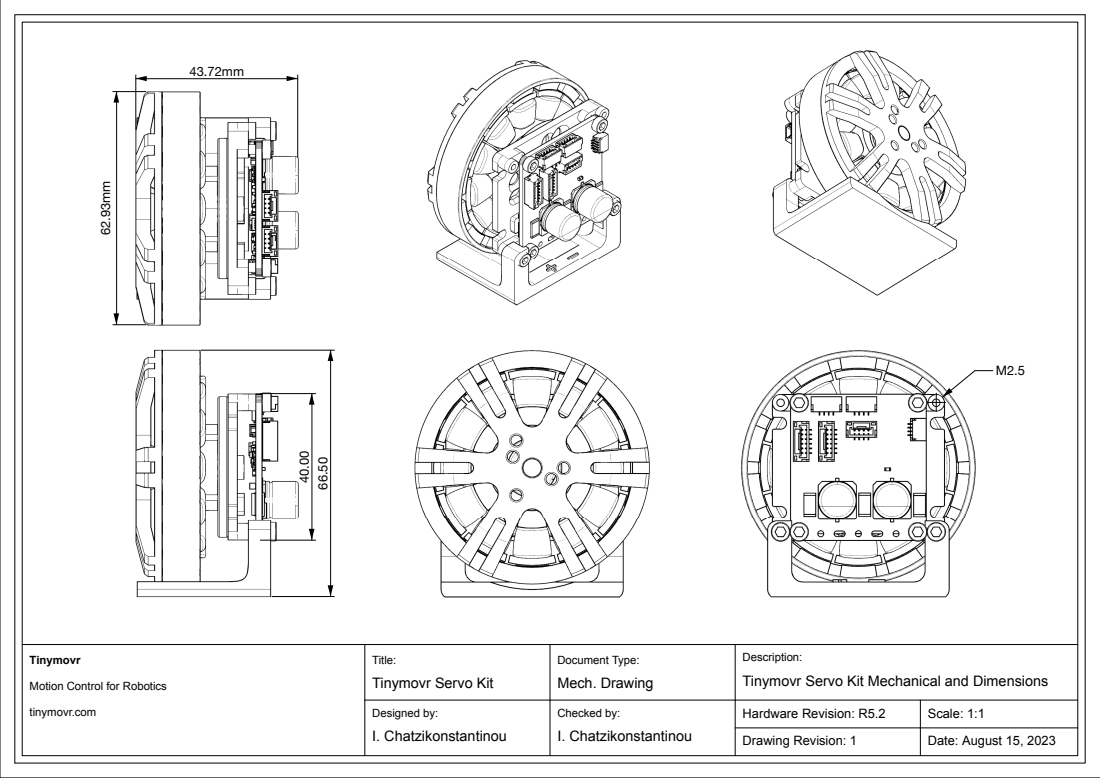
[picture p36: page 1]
I. Chatzikonstantinou; Tinymovr Servo Kit; Tinymovr Servo Kit Mechanical and Dimensions; Hardware Revision: R5.2; Scale: 1:1; Date: August 15, 2023; Document Type:; Checked by:; Drawing Revision: 1; Designed by:; Mech. Drawing

Motion Control for Robotics

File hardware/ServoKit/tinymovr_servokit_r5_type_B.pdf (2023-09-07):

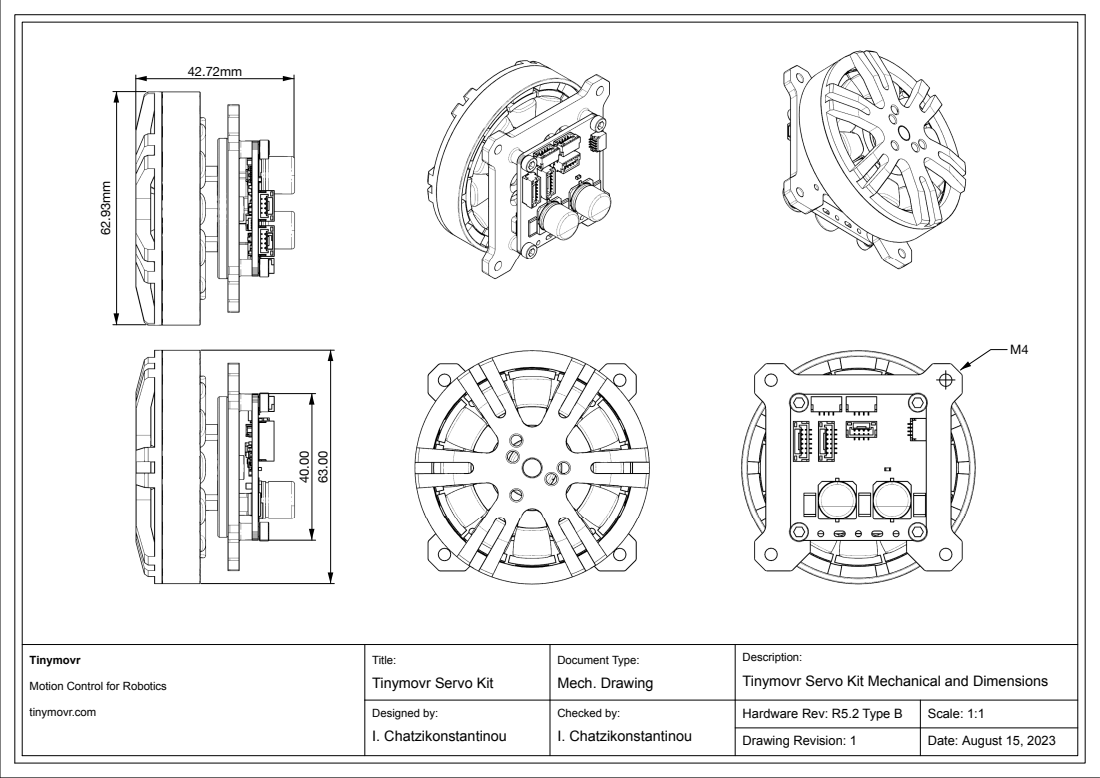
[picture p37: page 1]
I. Chatzikonstantinou; Drawing Revision: 1; Scale: 1:1; Date: August 15, 2023; Document Type:; Checked by:; Designed by:; Mech. Drawing; Tinymovr Servo Kit Mechanical and Dimensions

Title:
Tinymovr Servo Kit

Motion Control for Robotics

Hardware Rev: R5.2 Type B

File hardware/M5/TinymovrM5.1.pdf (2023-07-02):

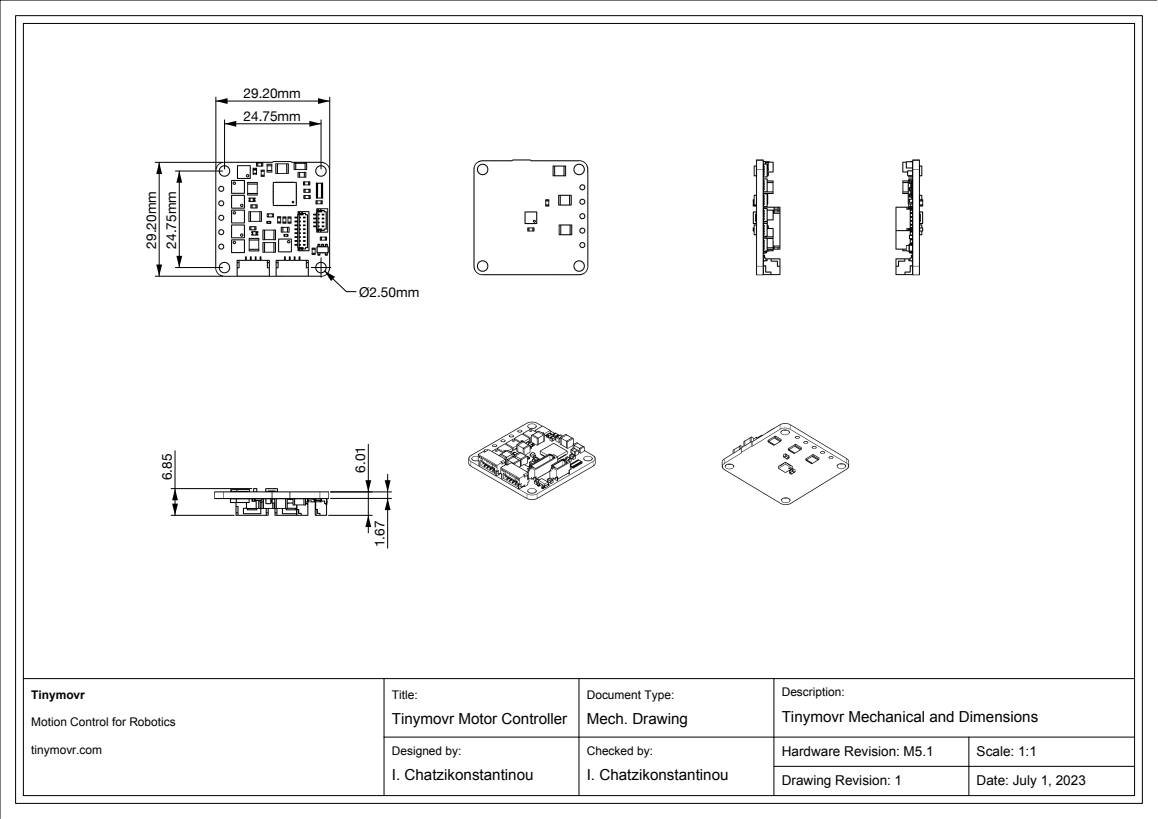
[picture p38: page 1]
Hardware Revision: M5.1; Date: July 1, 2023; Scale: 1:1; Document Type:; Description:; Designed by:; Checked by:; Mech. Drawing; Tinymovr Mechanical and Dimensions; Tinymovr; tinymovr.com; I. Chatzikonstantinou; Drawing Revision: 1

Title:
Tinymovr Motor Controller

Motion Control for Robotics

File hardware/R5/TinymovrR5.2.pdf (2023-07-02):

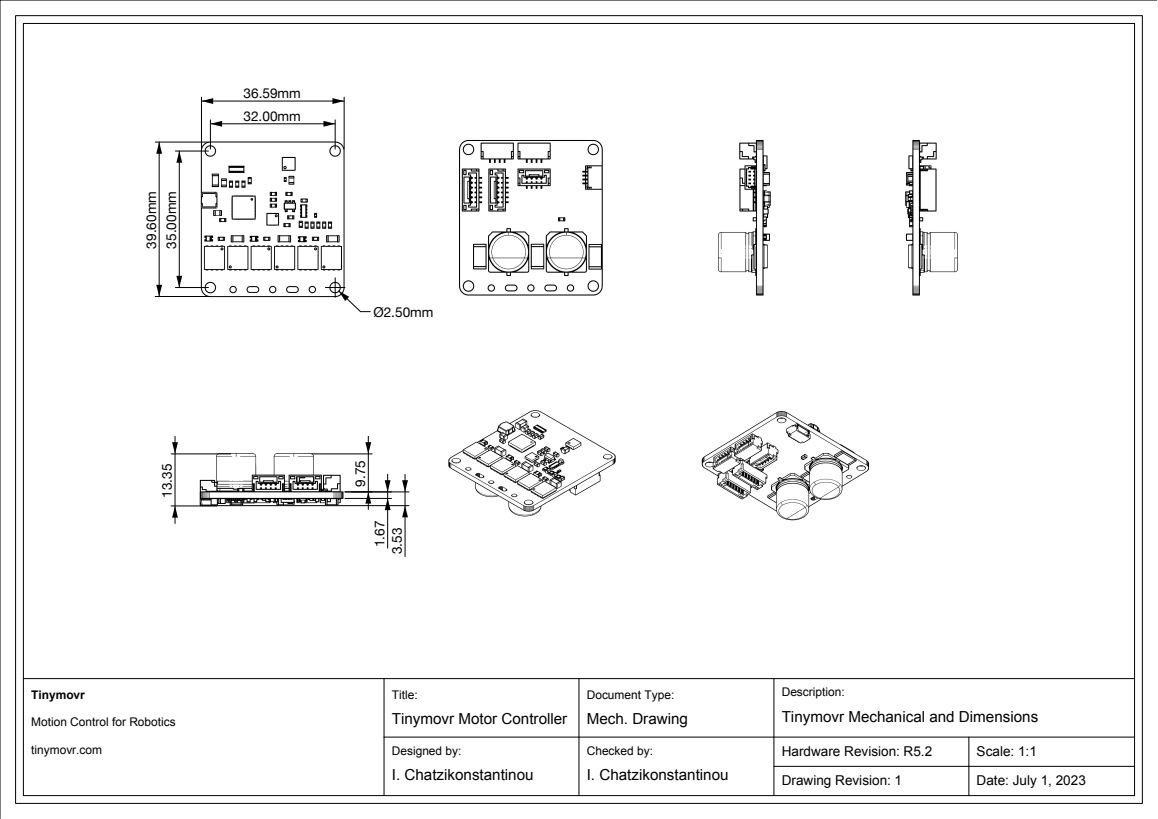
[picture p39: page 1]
Hardware Revision: R5.2; I. Chatzikonstantinou; Drawing Revision: 1; Designed by:; Tinymovr; tinymovr.com; Checked by:; Date: July 1, 2023; Scale: 1:1; Mech. Drawing; Document Type:

Description:
Tinymovr Mechanical and Dimensions

Title:
Tinymovr Motor Controller

Motion Control for Robotics

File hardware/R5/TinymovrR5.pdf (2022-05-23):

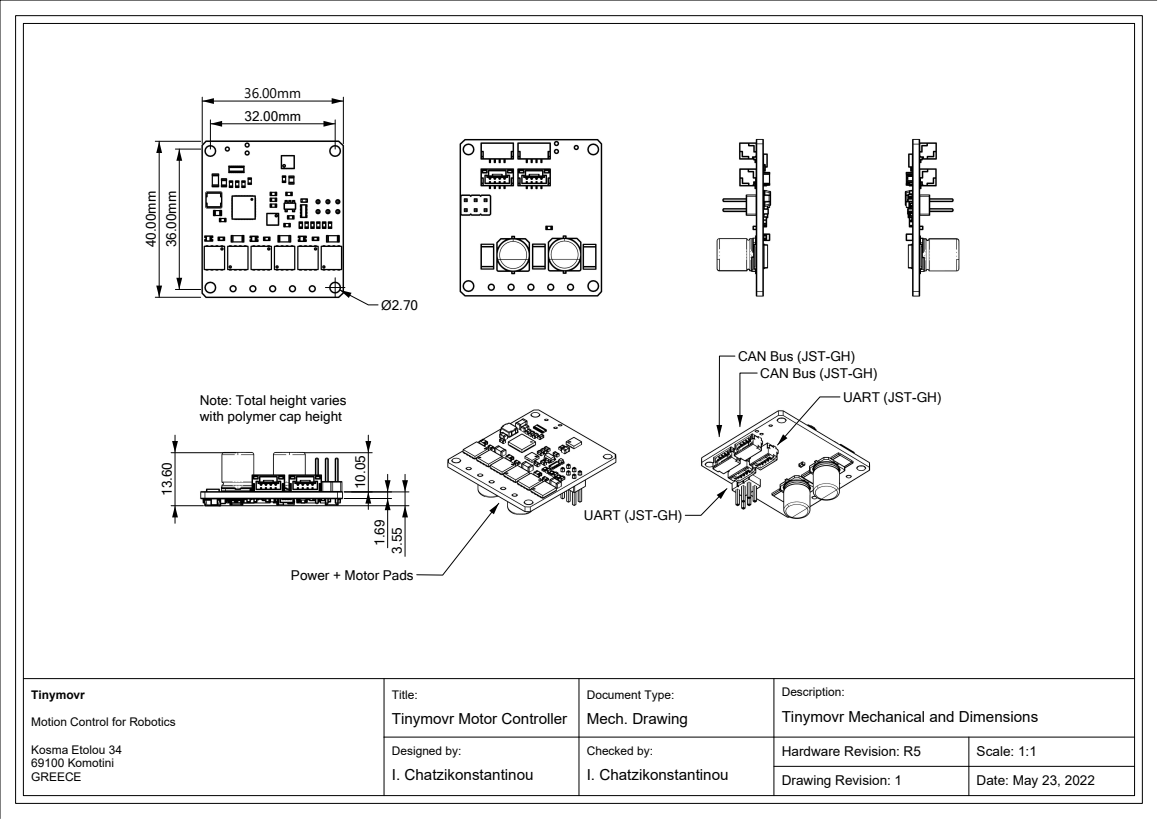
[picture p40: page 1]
Hardware Revision: R5; Date: May 23, 2022; Document Type:; Checked by:; Mech. Drawing; Tinymovr Mechanical and Dimensions; I. Chatzikonstantinou; Designed by:; Scale: 1:1; Tinymovr; Description:; Kosma Etolou 34 69100 Komotini GREECE; Drawing Revision: 1

CAN Bus (JST-GH)

Note: Total height varies
with polymer cap height

UART (JST-GH)

Power + Motor Pads

Title:
Tinymovr Motor Controller

Motion Control for Robotics

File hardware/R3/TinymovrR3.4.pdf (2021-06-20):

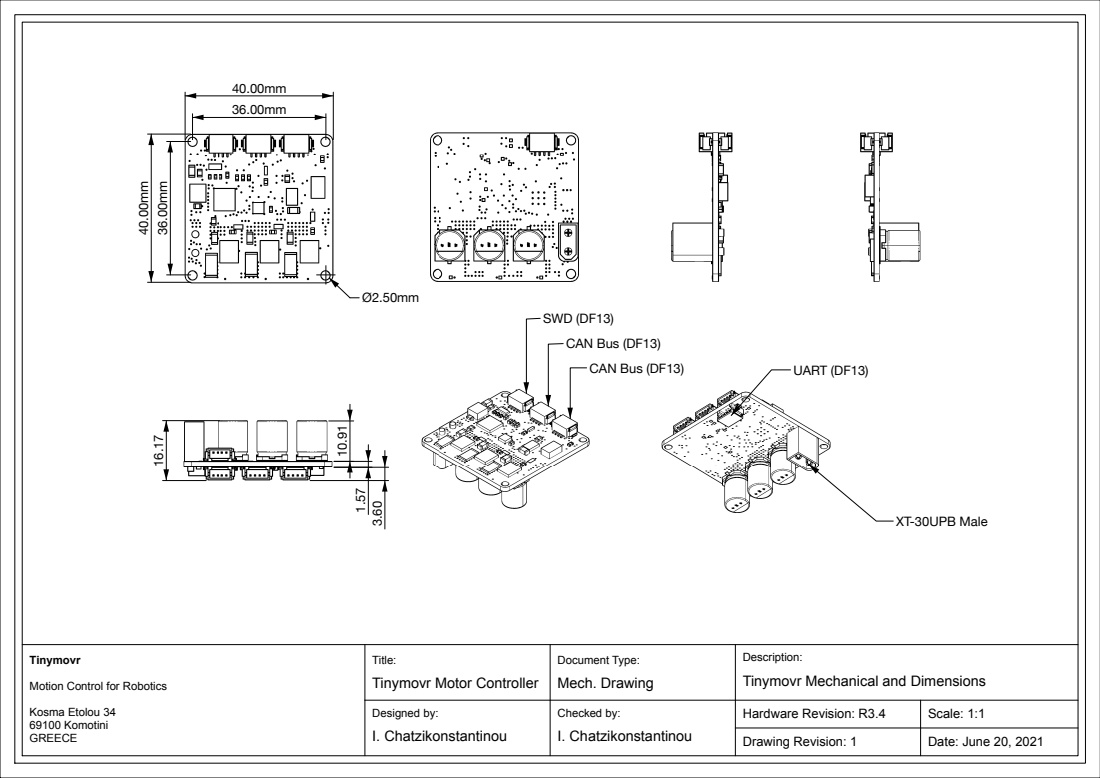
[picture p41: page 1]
Document Type:; Designed by:; Checked by:; Mech. Drawing; Tinymovr Mechanical and Dimensions; I. Chatzikonstantinou; Kosma Etolou 34 69100 Komotini; Drawing Revision: 1; Hardware Revision: R3.4; Scale: 1:1; Date: June 20, 2021; CAN Bus (DF13); SWD (DF13); XT-30UPB Male; UART (DF13)

Title:
Tinymovr Motor Controller

Motion Control for Robotics

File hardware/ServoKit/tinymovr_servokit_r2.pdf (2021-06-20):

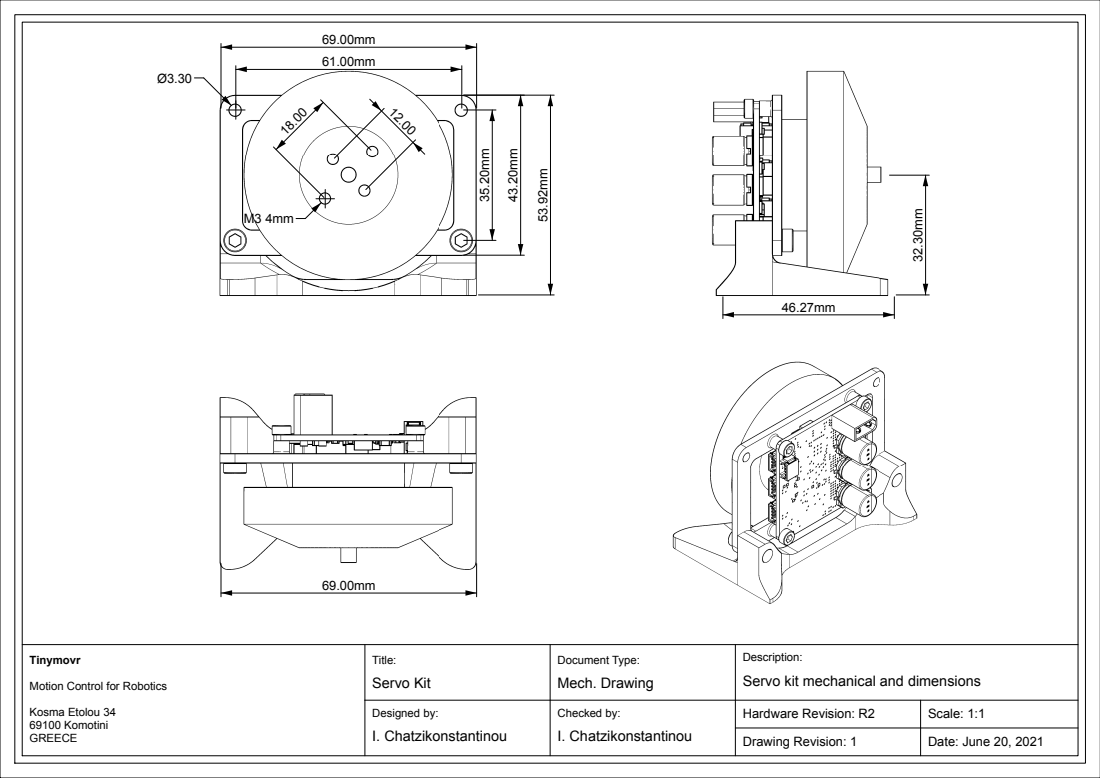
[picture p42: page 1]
Drawing Revision: 1; Hardware Revision: R2; Scale: 1:1; Date: June 20, 2021; Document Type:; Description:; Designed by:; Checked by:; Mech. Drawing; Servo kit mechanical and dimensions; I. Chatzikonstantinou; Servo Kit; Kosma Etolou 34 69100 Komotini

Motion Control for Robotics

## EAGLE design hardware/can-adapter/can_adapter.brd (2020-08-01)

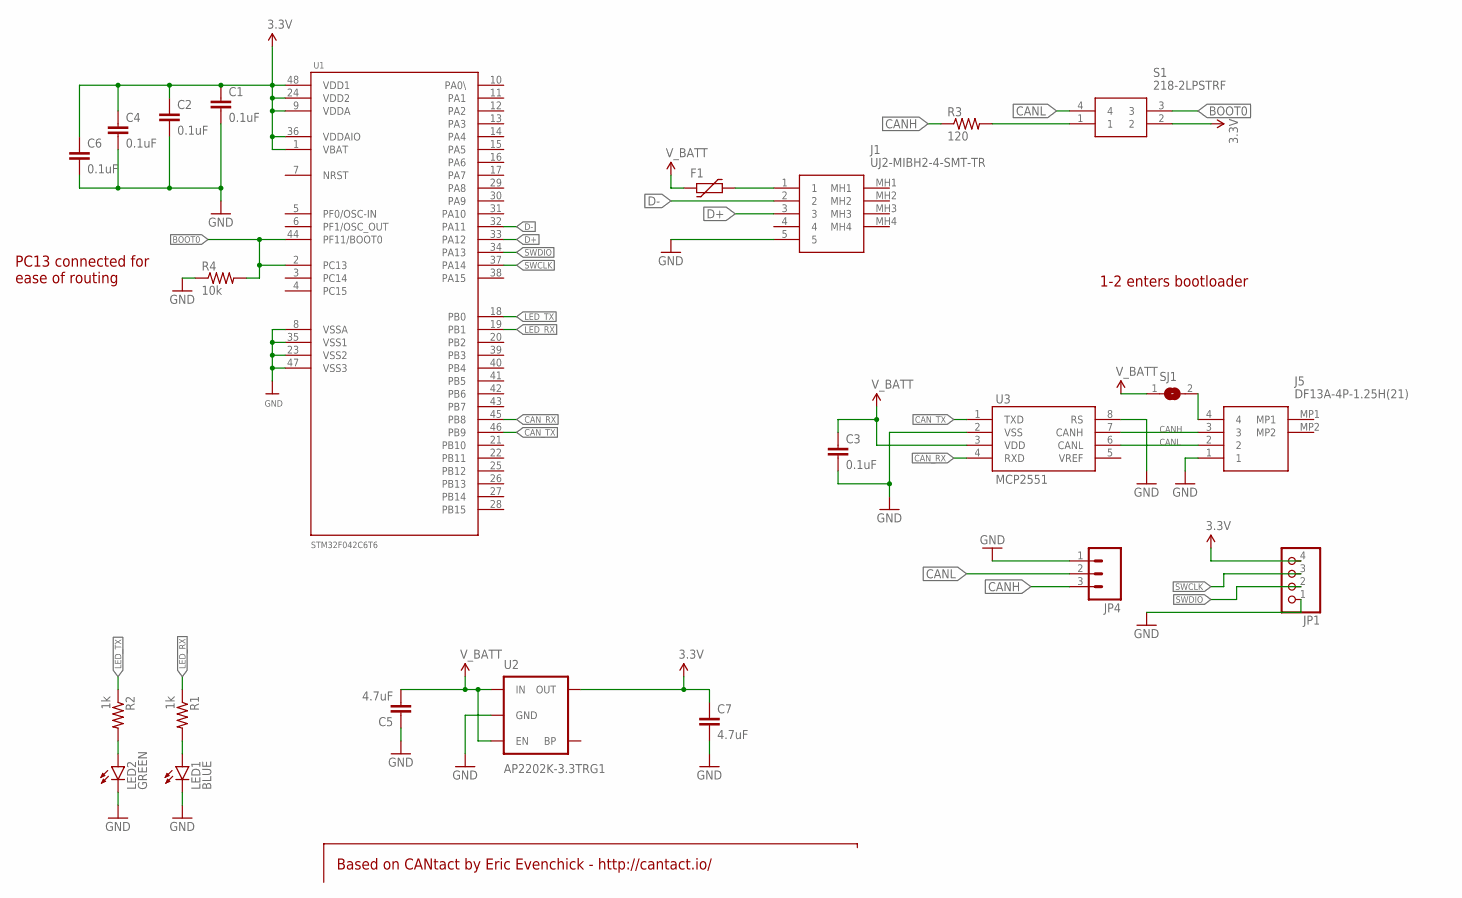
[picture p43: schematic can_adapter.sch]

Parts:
C1, C2, C3, C4, C6: 0.1uF; 0603-CAP
C5, C7: 4.7uF; 0603-CAP
F1: FUSE_PTC-0805; PTC0805
J1: UJ2-MIBH2-4-SMT-TR; UJ2MIBH24SMTTR
J5: DF13A-4P-1.25H(21); DF13A4P125H21
JP1: PINHD-1X04_2.54-S; 1X04-S
JP4: M03LOCK; 1X03_LOCK
LED1: BLUE; LED-0603
LED2: GREEN; LED-0603
R1, R2: 1k; 0603-RES
R3: 120; 0603-RES
R4: 10k; 0603-RES
S1: 218-2LPSTRF; 2182LPSTRF
SJ1: SJ
U1: STM32F042C6T6; LQFP48
U2: AP2202K-3.3TRG1; SOT23-5
U3: MCP2551; SO08

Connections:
3.3V: C1.1, C2.1, C4.1, C6.1, C7.1, JP1.4, S1.2, U1.1 (VBAT), U1.9 (VDDA), U1.24 (VDD2), U1.36 (VDDAIO), U1.48 (VDD1), U2.5 (OUT)
BOOT0: R4.2, S1.3, U1.2 (PC13), U1.44 (PF11/BOOT0)
CANH: J5.3, JP4.3, R3.1, U3.7 (CANH)
CANL: J5.2, JP4.2, S1.4, U3.6 (CANL)
CAN_RX: U1.45 (PB8), U3.4 (RXD)
CAN_TX: U1.46 (PB9), U3.1 (TXD)
D+: J1.3, U1.33 (PA12)
D-: J1.2, U1.32 (PA11)
GND: C1.2, C2.2, C3.2, C4.2, C5.1, C6.2, C7.2, J1.5, J5.1, JP1.1, JP4.1, LED1.C, LED2.C, R4.1, U1.8 (VSSA), U1.23 (VSS2), U1.35 (VSS1), U1.47 (VSS3), U2.2 (GND), U3.2 (VSS), U3.8 (RS)
LED_RX: R1.1, U1.19 (PB1)
LED_TX: R2.1, U1.18 (PB0)
unnamed: LED2.A, R2.2
unnamed: R3.2, S1.1
unnamed: J5.4, SJ1.2
unnamed: F1.2, J1.1
unnamed: LED1.A, R1.2
SWCLK: JP1.3, U1.37 (PA14)
SWDIO: JP1.2, U1.34 (PA13)
V_BATT: C3.1, C5.2, F1.1, SJ1.1, U2.1 (IN), U2.3 (EN), U3.3 (VDD)

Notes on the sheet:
Based on CANtact by Eric Evenchick - http://cantact.io/
PC13 connected for ease of routing
1-2 enters bootloader

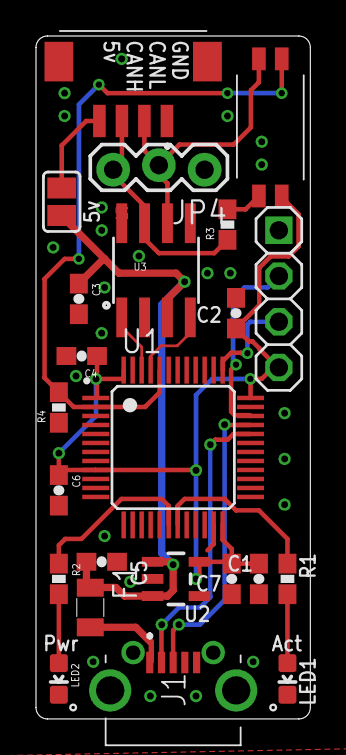
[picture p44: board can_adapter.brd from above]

Board: 2 copper layers, 15.2 x 37.9 mm, 23 parts (0 on the bottom side), 19 nets.

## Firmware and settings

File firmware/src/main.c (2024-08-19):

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

#include "src/common.h"
#include "src/system/system.h"
#include "src/uart/uart_lowlevel.h"
#include <src/sensor/sensor.h>
#include "src/observer/observer.h"
#include "src/adc/adc.h"
#include "src/motor/motor.h"
#include "src/controller/controller.h"
#include "src/gatedriver/gatedriver.h"
#include "src/timer/timer.h"
#include "src/can/can.h"
#include "src/nvm/nvm.h"
#include "src/watchdog/watchdog.h"

int main(void)
{
  	__disable_irq();
    system_init();
    UART_Init(); // Keep UART init before config load for now
    if (!nvm_load_config())
    {
        sensors_init_with_defaults();
        observers_init_with_defaults();
    }
    ADC_init();
    CAN_init();
    timers_init();
    Watchdog_init();
    __enable_irq();

    Controller_ControlLoop();
}

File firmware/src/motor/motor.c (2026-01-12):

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
#include <src/adc/adc.h>
#include <src/controller/controller.h>
#include <src/observer/observer.h>
#include <src/scheduler/scheduler.h>
#include <src/utils/utils.h>
#include <src/can/can_endpoints.h>
#include <src/motor/motor.h>

#if defined BOARD_REV_R32 || defined BOARD_REV_R33 || defined BOARD_REV_R5

static MotorConfig config = {
	.pole_pairs = 7u,
	.phase_resistance = MIN_PHASE_RESISTANCE,
	.phase_inductance = MIN_PHASE_INDUCTANCE,

	.I_cal = 6.0f,

	.resistance_calibrated = false,
	.inductance_calibrated = false,
	.poles_calibrated = false,

	.is_gimbal = false};

#elif defined BOARD_REV_M5

static MotorConfig config = {
	.pole_pairs = 7u,
	.phase_resistance = MIN_PHASE_RESISTANCE,
	.phase_inductance = MIN_PHASE_INDUCTANCE,

	.I_cal = 1.2f,

	.resistance_calibrated = false,
	.inductance_calibrated = false,
	.poles_calibrated = false,

	.is_gimbal = false};

#endif

static MotorState state = {0};

void motor_reset_calibration()
{
	config.pole_pairs = 7;
	// Important! We only reset resistance and 
	// inductance measurements if the motor is
	// not a gimbal, otherwise they will not
	// be recalibrated and will stay at default
	// values!
	if (!motor_get_is_gimbal())
	{
		config.phase_resistance = 0.1f;
		config.phase_inductance = 1e-5f;
		config.resistance_calibrated = false;
		config.inductance_calibrated = false;
	}
	config.poles_calibrated = false;
}

bool motor_calibrate_resistance(void)
{
    if (!motor_get_is_gimbal())
    {
        FloatTriplet I_phase_meas = {0.0f};
        FloatTriplet modulation_values = {0.0f};

		ADC_get_phase_currents(&I_phase_meas);

		float I_meas = I_phase_meas.A;
		float I_cal = motor_get_I_cal();
        float V_setpoint = 0.0f;
        uint32_t abnormal_condition_count = 0;

        for (uint32_t i = 0; i < CAL_R_LEN; i++)
        {
            ADC_get_phase_currents(&I_phase_meas);

            V_setpoint += CAL_V_GAIN * (I_cal - I_meas);
			I_meas += CAL_I_GAIN * (I_phase_meas.A - I_meas);

            // Debounced abnormal voltage check (after warm-up period)
            if (i > CAL_R_WARMUP_ITERATIONS)
            {
                if (V_setpoint > MAX_CALIBRATION_VOLTAGE && I_meas < MIN_CALIBRATION_CURRENT)
                {
                    abnormal_condition_count++;
                    if (abnormal_condition_count >= CAL_R_ABNORMAL_DEBOUNCE)
                    {
                        uint8_t *error_ptr = motor_get_error_ptr();
                        *error_ptr |= MOTOR_ERRORS_ABNORMAL_CALIBRATION_VOLTAGE;
                        gate_driver_set_duty_cycle(&three_phase_zero);
                        return false;
                    }
                }
                else
                {
                    abnormal_condition_count = 0;  // Reset counter if condition clears
                }
            }

            const float pwm_setpoint = V_setpoint / system_get_Vbus();
            SVM(pwm_setpoint, 0.0f, &modulation_values.A, &modulation_values.B, &modulation_values.C);
            gate_driver_set_duty_cycle(&modulation_values);
            wait_for_control_loop_interrupt();
        }
        
        const float R = our_fabsf(V_setpoint / I_cal);
        gate_driver_set_duty_cycle(&three_phase_zero);
        
        if ((R <= MIN_PHASE_RESISTANCE) || (R >= MAX_PHASE_RESISTANCE))
        {
            uint8_t *error_ptr = motor_get_error_ptr();
            *error_ptr |= MOTOR_ERRORS_PHASE_RESISTANCE_OUT_OF_RANGE;
            return false;
        }
        else
        {
            motor_set_phase_resistance(R);
        }
    }
    return true;
}


bool motor_calibrate_inductance(void)
{
    if (!motor_get_is_gimbal())
    {
        float V_setpoint = 0.0f;
        float I_low = 0.0f;
        float I_high = 0.0f;
        FloatTriplet I_phase_meas = {0.0f};
        FloatTriplet modulation_values = {0.0f};

        for (uint32_t i = 0; i < CAL_L_LEN; i++)
        {
            ADC_get_phase_currents(&I_phase_meas);
            if ((i & 0x2u) == 0x2u)
            {
                I_high += I_phase_meas.A;
                V_setpoint = -CAL_V_INDUCTANCE;
            }
            else
            {
                I_low += I_phase_meas.A;
                V_setpoint = CAL_V_INDUCTANCE;
            }
            const float pwm_setpoint = V_setpoint / system_get_Vbus();
            SVM(pwm_setpoint, 0.0f, &modulation_values.A, &modulation_values.B, &modulation_values.C);
            gate_driver_set_duty_cycle(&modulation_values);
            wait_for_control_loop_interrupt();
        }
        const float num_cycles = CAL_L_LEN / 2;
        const float dI_by_dt = (I_high - I_low) / (PWM_PERIOD_S * num_cycles);
        const float L = CAL_V_INDUCTANCE / dI_by_dt;
        gate_driver_set_duty_cycle(&three_phase_zero);
        if ((L <= MIN_PHASE_INDUCTANCE) || (L >= MAX_PHASE_INDUCTANCE))
        {
            uint8_t *error_ptr = motor_get_error_ptr();
            *error_ptr |= MOTOR_ERRORS_PHASE_INDUCTANCE_OUT_OF_RANGE;
            return false;
        }
        else
        {
            motor_set_phase_inductance(L);
            controller_update_I_gains();
        }
    }
    return true;
}

TM_RAMFUNC uint8_t motor_find_pole_pairs(uint32_t ticks, float mpos_start, float mpos_end, float epos_rad)
{
	const float mpos_diff = our_fabsf(mpos_end - mpos_start);
	float mpos_diff_rad = TWOPI * mpos_diff / ticks;
	const float pairs_f = epos_rad / mpos_diff_rad;
	const uint8_t pairs_i = (uint8_t)our_floorf(pairs_f + 0.5f);
	const float residual = our_fabsf(pairs_f - (float)pairs_i);

	if (pairs_i > MOTOR_MAX_POLE_PAIRS)
	{
		uint8_t *error_ptr = motor_get_error_ptr();
		*error_ptr |= MOTOR_ERRORS_POLE_PAIRS_OUT_OF_RANGE;
		return false;
	}
	else if (residual > 0.30f)
	{
		uint8_t *error_ptr = motor_get_error_ptr();
		*error_ptr |= MOTOR_ERRORS_POLE_PAIRS_CALCULATION_DID_NOT_CONVERGE;
		return false;
	}
	motor_set_pole_pairs(pairs_i);
	return true;
}

TM_RAMFUNC uint8_t motor_get_pole_pairs(void)
{
	return config.pole_pairs;
}

TM_RAMFUNC void motor_set_pole_pairs(uint8_t pairs)
{
	if (pairs >= 1u && pairs <= MOTOR_MAX_POLE_PAIRS)
	{
		config.pole_pairs = pairs;
		config.poles_calibrated = true;
	}
}

TM_RAMFUNC float motor_get_phase_resistance(void)
{
	return config.phase_resistance;
}

TM_RAMFUNC void motor_set_phase_resistance(float R)
{
	if ((R > MIN_PHASE_RESISTANCE) && ((R < MAX_PHASE_RESISTANCE) || motor_get_is_gimbal()))
	{
		config.phase_resistance = R;
		config.resistance_calibrated = true;
		if (config.resistance_calibrated && config.inductance_calibrated)
		{
			controller_update_I_gains();
		}
	}
}

TM_RAMFUNC float motor_get_phase_inductance(void)
{
	return config.phase_inductance;
}
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

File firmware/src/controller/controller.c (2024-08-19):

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
#include <src/system/system.h>
#include <src/sensor/sensor.h>
#include <src/observer/observer.h>
#include <src/adc/adc.h>
#include <src/motor/motor.h>
#include <src/gatedriver/gatedriver.h>
#include <src/utils/utils.h>
#include <src/scheduler/scheduler.h>
#include <src/can/can_endpoints.h>
#include <src/controller/controller.h>
#include "src/watchdog/watchdog.h"

void CLPreStep(void);
void CLPreCheck(void);
void CLControlStep(void);
static inline bool Controller_LimitVelocity(float min_limit, float max_limit, float vel_estimate,
                                                            float vel_gain, float *I);

static MotionPlan motion_plan;
static ControllerState state = {

    .state = CONTROLLER_STATE_IDLE,
    .mode = CONTROLLER_MODE_CURRENT,
    .errors = CONTROLLER_ERRORS_NONE,
    .is_calibrating = false,

    .I_phase_meas = {0.0f, 0.0f, 0.0f},
    .modulation_values = {0.0f, 0.0f, 0.0f},

    .Iq_estimate = 0.0f,
    .Id_estimate = 0.0f,

    .Ibus_est = 0.0f,
    .power_est = 0.0f,

    .pos_setpoint = 0.0f,
    .vel_setpoint = 0.0f,
    .vel_ramp_setpoint  = 0.0f,
    .Iq_setpoint = 0.0f,
    .Id_setpoint = 0.0f,

    .Vq_setpoint = 0.0f,

    .vel_integrator = 0.0f,

    .Iq_integrator = 0.0f,
    .Id_integrator = 0.0f,

    .t_plan = 0.0f
};

Statistics pre_cl_stats = {0};

#if defined BOARD_REV_R32 || BOARD_REV_R33 || defined BOARD_REV_R5

static ControllerConfig config = {
    .vel_limit = 300000.0f,
    .I_limit = 10.0f,
    .pos_gain = 20.0f,
    .vel_gain = 8.0e-5f,
    .vel_integral_gain = 0.00020f,
    .vel_integral_deadband = 200.0f,
    .I_bw = 2000.0,
    .I_gain = 0.0f,
    .Iq_integral_gain = 0.0f,
    .Id_integral_gain = 0.0f,
    .I_k = 0.3f,
    .vel_increment = 100.0f, // ticks/cycle
    .max_Ibus_regen = 0.0f,
    .max_Ibrake = 0.0f}; 

#elif defined BOARD_REV_M5

static ControllerConfig config = {
    .vel_limit = 100000.0f,
    .I_limit = 4.0f,
    .pos_gain = 8.0f,
    .vel_gain = 5.0e-5f,
    .vel_integral_gain = 0.00020f,
    .vel_integral_deadband = 200.0f,
    .I_bw = 2000.0,
    .I_gain = 0.0f,
    .Iq_integral_gain = 0.0f,
    .Id_integral_gain = 0.0f,
    .I_k = 0.3f,
    .vel_increment = 100.0f, // ticks/cycle
    .max_Ibus_regen = 0.0f,
    .max_Ibrake = 0.0f}; 

#endif

void Controller_ControlLoop(void)
{
    while (true)
    {
        state.warnings = 0;
        const float Iq = controller_get_Iq_estimate();
        const float Iq_trip = our_fmaxf(config.I_limit * I_TRIP_MARGIN, MIN_TRIP_CURRENT);
        if (our_fabsf(Iq) > Iq_trip)
        {
            state.errors |= CONTROLLER_ERRORS_CURRENT_LIMIT_EXCEEDED;
        }
        if (errors_exist() && (state.state != CONTROLLER_STATE_IDLE))
        {
            controller_set_state(CONTROLLER_STATE_IDLE);
        }

        if (state.state == CONTROLLER_STATE_CALIBRATE)
        {
            state.is_calibrating = true;
            system_reset_calibration();
            // TODO: sensors_calibrate should also return bool, and be integrated in the calibration sequence
            if (ADC_calibrate_offset() && motor_calibrate_resistance() && motor_calibrate_inductance())
            {
                (void)(sensors_calibrate());
            }
            state.is_calibrating = false;
            controller_set_state(CONTROLLER_STATE_IDLE); 
        }
        else if (state.state == CONTROLLER_STATE_CL_CONTROL)
        {
            // Check the watchdog and revert to idle if it has timed out
            if (Watchdog_triggered())
            {
                controller_set_state(CONTROLLER_STATE_IDLE);
                Watchdog_reset();
            }
            else if ((motor_get_is_gimbal() == false) && pre_cl_stats.size < MAX_CL_INIT_STEPS)
            {
                CLPreStep();
            }
            else if ((motor_get_is_gimbal() == false) && pre_cl_stats.size == MAX_CL_INIT_STEPS)
            {
                state.pos_setpoint = observer_get_pos_estimate(&position_observer);
                CLPreStep();
                CLPreCheck();
            }
            else
            {
                CLControlStep();
            }
        }
        wait_for_control_loop_interrupt();
    }
}

TM_RAMFUNC void CLPreStep(void)
{
    gate_driver_set_duty_cycle(&three_phase_zero);
    // Should approximate zero as from Kirchoff
    float Iphase_meas_sum = state.I_phase_meas.A + state.I_phase_meas.B + state.I_phase_meas.C; 
    update_statistics(&pre_cl_stats, Iphase_meas_sum);
}

TM_RAMFUNC void CLPreCheck(void)
{
    if (calculate_standard_deviation(&pre_cl_stats) > PRE_CL_I_SD_MAX)
    {
        state.errors |= CONTROLLER_ERRORS_PRE_CL_I_SD_EXCEEDED;
    }
}

TM_RAMFUNC void CLControlStep(void)
{
    switch (state.mode)
    {
        case CONTROLLER_MODE_TRAJECTORY:
        state.t_plan += PWM_PERIOD_S;
        // This will set state.pos_setpoint state.vel_setpoint (in user frame)
        if (!traj_planner_evaluate(state.t_plan, &motion_plan))
        {
            // Drop to position mode on error or completion
            controller_set_mode(CONTROLLER_MODE_POSITION);
            state.t_plan = 0;
        }
        break;
        case CONTROLLER_MODE_HOMING:
        // This will set state.pos_setpoint state.vel_setpoint (in user frame)
        if (!homing_planner_evaluate())
        {
            // Drop to position mode on error or completion
            controller_set_mode(CONTROLLER_MODE_POSITION);
        }
        break;
        default: break;
    }

    // Sudden changes in velocity setpoints would lead to sudden
    // jerks and current spikes, so a ramping function makes transitions
    // a bit smoother.
    if (config.vel_increment > 0)
    {
        state.vel_ramp_setpoint  += our_clamp(state.vel_setpoint - state.vel_ramp_setpoint, -config.vel_increment, config.vel_increment);
    }
    else
    {
        state.vel_ramp_setpoint  = state.vel_setpoint ;
    }

    // The actual velocity setpoint and the one used by the velocity integrator are
    // separate because the latter takes into account a user-configurable deadband
    // around the position setpoint, where the integrator "sees" no error
    float vel_setpoint = state.vel_ramp_setpoint ;
    float vel_setpoint_integral = state.vel_ramp_setpoint ;

    if (state.mode >= CONTROLLER_MODE_POSITION)
    {
        const float delta_pos = get_diff_position_sensor_frame(state.pos_setpoint);
        const float delta_pos_integral = sgnf(delta_pos) * our_fmaxf(0, fabsf(delta_pos) - config.vel_integral_deadband);
        vel_setpoint += delta_pos * config.pos_gain;
        vel_setpoint_integral += delta_pos_integral * config.pos_gain;
    }

    const float vel_estimate = observer_get_vel_estimate(&position_observer);
    float Iq_setpoint = state.Iq_setpoint;
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

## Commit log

2020-07-26 add motor stand stls
    [motor_stand_magnet.stl, motor_stand_pointer.stl]
2020-08-01 add CANdapter schematic and board files
    [canable_candapter.brd, canable_candapter.sch]
2020-08-04 Add CANable support to Studio (#11)
    * remove arduino interface
    * canable support
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2020-08-11 Rename CANdapter -> CAN Adapter, add case STL (#15)
    * rename adapter references
    * rename motor stand dir
    * add STL
    * update readme
    [can_adapter.brd, can_adapter.sch, can_adapter.stl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]
2020-08-12 CAN Bus client improvements (#16)
    * improve device detection
    * simplify CAN initialization
    * require python-can 4.0 prerelease
    * fix identifying of calibration state
    * improve intro message
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2020-08-12 Update docs with latest instructions (#17)
    * bump version
    * improve instructions and add links
    * add mounting figure
    * remove obsolete notice
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2020-08-17 Add command line options documentation (#22)
    * Command line option documentation
    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
2020-08-19 Phase currents endpoint (#26)
    * add phase current endpoint
    * update error list
    * conditional endpoints based on fw version
    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
2020-08-21 Add firmware to repository (#20)
    * initial commit
    * add sdk patch
    * update docs for firmware development
    * add link to firmware
    * more conservative tuning
    * add explicit attribution and license info
    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
2020-08-23 Update firmware flashing procedure in docs (#29)
    * update firmware flashing procedure
    * add board dimensions
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2020-08-25 Update CAN adapter case model (#31)
    [can_adapter.stl]
2020-09-04 Export and restore board configuration (#37)
    * add endpoint save and restore maps
    * improve endpoint maps
    * save-restore config methods and endpoint setters support keyword arguments
    * recursive processing of endpoints for de-serialization
    * improve formatting and handling of exported config files
2020-09-07 Studio/fix current setter (#42)
    * fix endpoint labels assertion
    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
2020-09-07 Add 5V tolerance warning
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2020-09-25 Python type-safety and in-silico Tinymovr (#48)
    * add test bus
    * remove unused class
    * make type safe
    * linting and formatting
    * move methods out of class
    * extract node and endpoint id
    * basic test agent
    * improve test class
    * populate actual testing values
    * make codec part of interface
    * fix endpoint id
    * implement more endpoints
    * add docs
    * very basic simulation
    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
    [can.py]
2020-09-28 Refactor to make studio more generic (#52)
    * make codecs generic
    * make iface base class generic
    * fix imports
    * make can-agnostic
    * update docs
    * fix function call
    * make endpoints can-specific
    [can.py]
2020-10-10 Fix set_vel_setpoint (0x00D) data decoding (#59)
    * fix endpoint data decoding
    * update gitignore
    * fix patch
    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
    [config.h]
2020-10-16 Improve idle power (#62)
    * elcipse settings
    * change buck voltage 12v -> 10v for efficiency
    * improve comments
    * introduce R33.3 shunt scaling factor
    * experimental clock divider (not working yet!)
    * fix endpoint
    [adc.c, adc.h, config.h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]
2020-10-17 dq Current Limiter (#44)
    * initial dq limiter
    * inverse sqrt
    * update constants
    * remove delay
    * use -O2 compiler optimization
    * fix misra 12.1
    [config.h, controller.c, main.c]
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2020-10-21 Add R3.3 board step file (#66)
    [TinymovrR3.3.step]
2020-10-31 Fix uart handler (#72)
    * only disable rx interrupt if not sending msg
    * fix inductance scaling factor
    * add uart documentation
2020-11-02 Tests and CI for Tinymovr Studio (#73)
    * rename ci script
    * remove obsolete tests
    * add basic getter test
    * add python ci script
    * fix import
    * matplotlib headless import
    * change test names
    * add setters test
    * check velocity instead of position
    [can.py]
2020-11-04 Units and scales (#58)
    * add units infrastructure using pint
    * replace references to cpr with ticks
    * update units and defaults
    * make endpoints use units
    * attempt at pretty printing quantities
    * add vbus endpoint
    * fix tuple
    * update unit conversions
    * include unit registry in shell
    * plotter ignoring units for now
    * only redraw canvas
    * use units in tests
    * fix unit
    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
    [controller.c, motor.c, motor.h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]
2020-11-07 Update magnet mount docs (#75)
    * add bootloader test script
    * update magnet mount instructions
    * typing imports
2020-11-13 Fixes for units in Studio and testing improvements (#76)
    * express unit scales in prefixes
    * handle case of no arguments
    * Improve in silico Tinymovr
    * use intenum
    * expand testing framework
    * update docs for new in silico tinymovr
    * update errors
2020-11-13 Update CANine CAN Adapter schematics and models (#77)
    * update can adapter
    * update case
    [CANine.brd, CANine.sch, can_adapter.stl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]
2020-11-16 Upload devkit models (#79)
    * add devkit_alpha2 models
    * reorganize folders
    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
    [DevKit_alpha_magnet.stl, DevKit_alpha_pointer.stl, motor_stand_magnet.stl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]
2020-11-21 Validation tests for boards (#82)
    * initial tests for board
    * only test simulation in ci
    * reset tests after each sequence
    * add more validation tests
    * add board config save load erase tests
    * variable
    * fix calls to sleep
    * use units for comparison
2020-11-21 Refactor control and calibration loops (#69)
    * basic scheduler
    * perform all tasks on main loop using scheduler
    * project settings
    * refactor calibration functions
    * enable a few additional warnings
    * introduce low-level uart handler
    * move function to ram
    * factor out low level uart functions
    * update project settings
    * fix some misra errors
    * merge master
    * variable name
    * increase velocity test range
    * measure total and busy cycles in scheduler
    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
    [adc.c, adc.h, calibration.c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]
2020-11-22 More board tests (#83)
    * fix setstate fsm
    * add state fsm tests
    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
    [config.h, controller.c]
2020-11-28 Add tests related to velocity and current limits (#85)
    * limits tests initial commit
    * forgot module
    * only test velocities at the end of the test cycles
    * stricter deviation
    * add shortcut functions
    * add limits tests
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2020-12-21 Improve error reporting (#92)
    * add erro codes per system module
    * implement handlers
    * complete implementations
    * introduce presenter class, pass tests
    * return detailed errors
    * fix names
    * return detailed error
    * syntax
    * fix function declaration
    * fix calibration calls
    * fix some misra violations
    * refactor error mechanism
    * fully implement state object
    * adapt unit testing to newest error handling scheme
    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
    [calibration.c, can.c, common.h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]
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2020-12-28 Hard limits for velocity and current (#95)
    * use intrinsics if available
    * add min function
    * units
    * impose hard limits to velocity and current
    * rename function
    * include
    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
2020-12-31 Expose integrator gains endpoint (#96)
    * add endpoints
    * add integrator endpoints
    * fix units
    * update endpoint addresses
    * set default integrator gain
    * add integrator gain to UART protocol
    * formatting
    * add more tests for invalid values
    * use tmtestcase base class
    * increase comm timeout
    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
    [can.py, config.h, controller.c]
2020-12-31 Fix DWT register access (#99)
    * use correct dwt registers
    * test dwt timings
    [common.h, scheduler.c, system.c]
2021-01-15 Add encoder magnet jig STL (#105)
    [magnet_jig.stl]
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2021-01-16 Improve scheduler (#106)
    * concat redundant functions
    * optimize wfi call and clearing of interrupts
    * move total cycle timing calculation to interrupt handler
    * reduce interval
    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
2021-01-20 Gimbal mode (#108)
    * add motor config endpoints
    * add is_gimbal attribute and accessors
    * skip calibration of R, L is motor type is gimbal
    * separate control loop path for gimbal motors
    * update client endpoints
    * add separate current setpoint for gimbal calibration
    * move e angle calculation
    * update endpoints
    * reduce gains a bit
    * implement velocity in rad/s
    * fix Vq control
    * accept large inductance and resistance values if motor is gimbal
    * fix uart RL endpoints
    * update cal gain
    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
    [calibration.c, config.h, controller.c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]
2021-01-26 Improve docs and tests (#110)
    * add parameter persistence test
    * add guidelines for terminating CAN bus
    * reformat warnings
    * improve instructions
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2021-02-07 Prevent change in state while calibrating (#119)
    * prevent change in state while calibrating
    * add tests
    * probe while waiting for calibration
    * inform user that calibration is ongoing
    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
    [config.h, controller.c]
2021-02-13 Calibrate eccentricity (#112)
    * initial implementation
    * functioning prototype
    * use stack for temp array
    * convert indentation to spaces
    * modify patch to cover startup unit as well
    * changes related to misra-c compliance
    * fixed name appearing as reserved
    * reduce calibration times a bit
    * cleanup calibration routines
    * reenable building tinymovr fw
    * move wait block to function
    * fix some compile and link flags
    * add qorvo deps
    * really? pythom?
    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
    [calibration.c, config.h, controller.c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]
2021-03-06 Upload dev kti r2 step and stl files (#121)
    [tinymovr_devkit_r2.stp]
2021-03-07 Add STEP files and BOM for the ACT8.3 actuator (#122)
    * Add STEP files and BOM for the ACT8.3 actuator
    * update bom
2021-03-11 Correct bearing size
2021-03-18 Fix direction calibration (#123)
    * add swapping phases
    * remove encoder direction property
    * update calibration to swap motor phases instead of encoder direction
    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
    [adc.c, calibration.c, config.h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]
2021-03-27 Improvements in version checking (#126)
    * rename can bus module
    * use control state and mode enumeration labels
    * add min studio version requirement and endpoint
    * add min version requirement
    * add version checks
    * fix badges
    * Fix version tag
    * update tests
    * fix return value
    * update version
    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
    [config.h]
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2021-03-30 Better fault handler using Segger RTT (#130)
    * test
    * bump gate driver current
    * add segger RTT-based fault handler
    * remove WWDT from project
    * cppcheck fix
    * remove rtt from cppchecks
    [calibration.c, can.c]
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2021-04-03 Gimbal Improvements (#134)
    * allow setting calibration current
    * bump gains a bit
    * add gimbal test
    * remove uncertain check
    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
2021-04-12 Set Rotor Position Offset (zero position) and Rotor Direction (#136)
    * docs: gimbal mode clarification
    * chore: ignore vscode
    * refactor: move some variables to defines
    * refactor: can includes
    * feat: introduce user frame of reference
    * docs: update api
    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
2021-05-07 (docs) Update documentation with error code descriptions, fix errors (#141)
    * increase current limit
    * add error codes
    * fix uart doc errors
    [config.h]
2021-06-01 Trajectory planner (#144)
    * Initial planner implementation
    * optimize function
    * add planner error handling
    * better error handling
    * add time limited and accel limited implementations
    * bump uart buffer size
    * add hardware sqrt
    * use local struct for planner
    * add can endpoints
    * add plan endpoints
    * fix planning
    * fully working prototype
    * update planner API
    * add serial protocol planner commands
    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
    [common.h, config.h, controller.c]
2021-06-19 Fix planner pos offset (#147)
    * use controller calls to update setpoints in user frame
    * fix definition
    * add vscode settings
    * functions to ram
    * bump fw version
    [config.h, controller.c]
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2021-06-22 Regression testing for offset and trajectory planner (#149)
    * improve error logging
    * rename model file
    * increase pos p-gain
    [tinymovr_servokit_r2.stp]
2021-07-31 Migrate CANine docs and hardware schematics to own repo (#153)
    * migrate canine docs
    * migrate canine hardware
    [CANine.brd, CANine.sch, case.stl]
2021-09-24 One-shot (read/write) endpoints, VBus filtering (#155)
    * pass rtr and buffer length arguments to can handlers
    * fix function signature
    * add filtering to vbus value
    * fix references
    * fix double constant
    * fix function signature
    * implement rw endpoints
    * update insilico tests
    * update rw endpoints
    * fix var
    * add declarations
    * name
    * add version compatibility test
    * improve messaging when incompatible versions found
    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
    [adc.c, adc.h, can.c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]
2021-11-20 revert bug in frequency calculation
    [common.h]
2021-12-05 Minor firmware refactor, fix distribution bugs (#168)
    * remove unused function
    * cleanup/improve utility functions
    * update path
    * minor naming changes
    * add board revisions as macros, remove runtime check
    # Conflicts:
    # firmware/src/config.h
    # firmware/src/encoder/encoder.c
    * remove dry-run option
    * encoder naming
    * inline function
    * fix version setting
    * debug flags
    * add wiring diagram
    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
    [calibration.c, can.c, config.h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]
2022-02-07 Antihun and bugfixes (#171)
    * move R and L to separate endpoints
    * bump versions
    * fix reported version error
    * antihunt window
    * rename to deadband
    * better antihunt implementation
    * use own functions to move to ram
    * fix tests
    * bump reported version
    * update api reference
    * fix board version
    * unpack dictionary before passing as argument
    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
    [config.h, controller.c]
2022-02-11 Housekeeping and generic improvements (#173)
    * Conditionally define CAN bus pin config
    * automate resistor value selection
    * remove redundant vars
    * inline functions
    * inline more utility functions
    * fix condition
    * init list
    [adc.h, calibration.c, can.c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]
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2022-03-27 Hall sensor and observer improvements (#176)
    * introduce multiple encoders
    * remove command
    * hall effect sensor test rig
    * introduce hall sensor in configuration
    * add encoder type getter
    * add hall sequence calibration
    * more robust comparison
    * update hall sensor implementation
    * polymorphic encoder
    * de/serialization of encoder config
    * fix redefinition
    * guard
    * also set pole pairs
    * assign pointers
    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
    [adc.h, calibration.c, can.c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]
2022-04-11 Calibration fixes (#178)
    * add avlos config files and initial spec
    * reset motor calibration everytime
    * use a common calibration reset entry point
    * add test for re-calibration
    * reinstate separate calibration state variable
    * disable gate driver prior to updating motor parameters
    * reset observer and wait for it to settle
    * separate init from reset
    * improve recalibrate test
    [calibration.c, common.h, controller.c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]
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2022-04-16 rearrange the hardware directory (#180)
    [DevKit_alpha_magnet.stl, DevKit_alpha_pointer.stl, tinymovr_servokit_r2.stp]
2022-04-27 Handle individual board revisions (#181)
    * change board revision def
    * handle building different board revisions
    * bump python version
    * fix parameter value
    * pass python version as string
    * add action arguments for board revisions
    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
    [adc.h, can.c, common.h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]
2022-05-15 fix motor config docs
2022-05-16 fix gimbal regression bug
    [motor.c]
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2022-07-09 Fix saving and exporting config (#189)
    * save absolute encoder config
    * handle units in import-export
    * better handling of values
    * remove import
    * print exported and restored endpoints
    * bump sim version
    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
    [config.h, nvm.c]
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2022-08-13 Add Hall effect sensor documentation (#196)
    * title
    * add hall effect sensor docs
    * add task for building docs
    * add hall pinout figure
2022-08-17 CAN Timeout Watchdog (with WWDT) (#198)
    * Added watchdog .c and .h
    * Can endpoints added, untested
    * Unit32 timer, and moved check to CLControlStep
    * Comments/cleanup
    * API documentation
    * Timing implemented with WWDT
    * Cycles changed to uint16
    * add missing include
    * add unit test
    * add license header
    * Watchdog timeout maximum cap
    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
    [can.c, common.h, config.h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]
2022-09-04 Fix some omissions in Hall effect sensor documentation (#204)
    * fix some omissions in documentation
    * reorder sections
2022-09-25 Velocity ramping (#206)
    * Ramp added with get/set endpoint
    * Cleanup
    * allow setting zero to ramp
    * refactor velocity ramping
    * update flags for newer gcc
    Leaving -g would result in the error described here: https://community.arm.com/support-forums/f/compilers-and-libraries-forum/51596/lto-linker-error-with-gnu-arm-10-3-2021-07
    * add velocity ramp test
    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
    [calibration.c, controller.c]
2022-10-02 Hall mode update (#205)
    * New hall calibration sequence and SPI functions
    * Python and docs cleanup
    * fix comment
    * improve error description
    * only update sector if different
    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
    [calibration.c, ssp_func.c]
2022-10-15 add servokit r5 3d models
    [tinymovr_servokit_r5_part1.stl, tinymovr_servokit_r5_part2.stl]
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2023-04-06 1.x version series (#243)
    * Completely rewritten comms layer (#201)
    * update configuration
    * remove old endpoints
    * update reference
    * update include path
    * use correct endpoint reference
    * update function name
    * update function name
    * fix function signatures
    * fix generation
    * update setter
    * fix var scope
    * update names
    * rename prototypes
    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
    [adc.c, adc.h, calibration.c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]
2023-04-10 Fix auto discovery of devices in Studio (#251)
    * use alternative slcan interface with autodiscovery
    * add simple unit test for series testing
    * include package data
2023-04-29 Suggest studio version if incompatible (#258)
    * flush rx buffer
    * limit trials
    * report version if incompatible
    * add resources for dark and retina modes
    * use timeout
    * add about box with attribution
    * dark mode support
    * handle case where no compatible version is reported
    * properly deal with division by zero
    * add resources to manifest
    [can.c, config.py]
2023-04-30 Add Time-Limited Trajectory Planner Endpoints (#260)
    * save trajectory planner config
    * reset data length before calling callback
    * update protocol
    * standardize function naming
    * improve reporting of incompatible versions
    * add time-limited trajectory planner tests
    [can.c, config.py, controller.c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]
2023-05-14 Sensorless homing (#259)
    * add homing planner
    * add homing docs
    * revise docs
    * rename functions
    * update protocol, add warnings endpoint
    * remove erroneous import
    * add home endpoint
    * add flux braking to documentation
    * take homing timeout into account
    * add homing unit test
    * add homing case
    * reset timer
    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
    [controller.c, homing_planner.c]
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2023-05-26 fix error message display
    [config.py]
2023-06-03 fix firmware hardware revision variants
    [common.h]
2023-07-02 add M5 gimbal motor bracket
    [gimbal_bracket.stp]
2023-07-02 update model
    [gimbal_bracket.stp]
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2023-07-08 write to GP0 register when resetting anyway
    [system.c]
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2023-07-16 correctly return encoder estimates in user frame
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2023-08-14 update servo kit models
    [tinymovr_servokit_r5_part1.stl, tinymovr_servokit_r5_part2.stl, tinymovr_servokit_r5_type_A_part2.stl]
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2023-08-31 add gate driver error status
    [system.c]
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2023-09-05 fix some offset related errors
    [calibration.c]
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2023-09-13 fix uart commands
2023-09-18 fix hall error being misplaced as motor error
    [calibration.c]
2023-09-19 reset calibration
2023-09-21 disable driver errors returning spurious values
    [system.c]
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2023-11-05 fix hall setup commands
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2023-12-09 implement some missing functions
    [controller.c, observer.c, observer.h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]
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2024-01-09 fix timer frequency
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2024-02-06 fix sensor sector calculation
    [observer.h]
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2024-03-13 fix calibration frame issues
    [sensor.c, sensor.h]
2024-03-13 fix eccentricity and frames calibration
    [sensors.c]
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2024-03-17 fix velocity limiting issue
    [controller.c]
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2024-03-20 fix hall sector count
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2024-04-04 reset observer state on change
    [observer.h, sensors.c]
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2024-04-19 change scheduler error to warning
    [scheduler.c]
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2024-05-03 implement correct SPI delays according to amt22 datasheet
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2024-05-29 improve pole pair calibration error reporting
    [common.h, motor.c, sensor.c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]
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2024-06-06 fix erroneous return during transform derivation
    [sensors.c]
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2024-07-07 fix saving and validating to nvm
    [nvm.c]
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2024-08-19 fix calibration sequence
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2026-01-09 fix: Add debouncing and warm-up to resistance calibration voltage check
    Fixes random false positives in MOTOR_ERRORS_ABNORMAL_CALIBRATION_VOLTAGE
    that caused identical motors to randomly pass/fail calibration across all
    board and motor types.
    Root causes addressed:
    - Stale data bug: Check now uses fresh filtered current after update
    - No debouncing: Added 300-iteration (15ms) debounce window
    - No warm-up: Added 1500-iteration (75ms) warm-up period
    Changes:
    - Add CAL_R_WARMUP_ITERATIONS and CAL_R_ABNORMAL_DEBOUNCE constants
    - Move abnormal voltage check after I_meas update (line 97)
    - Require condition to persist for 300 consecutive iterations
    - Skip check during initial 75ms transient peri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
    [motor.c, motor.h]
2026-01-09 test: Make random position control test more robust to power line noise
    Improves test_f_random_pos_control reliability by reducing sensitivity to
    power line inductance and noise-induced settling issues.
    - Reduce velocity limits (100k→80k for M5, 150k→120k for R3/R5)
    - Add velocity deadband (500/1000) to filter small oscillations
    - Reduce position step size (10k→8k for M5, 24k→18k for R3/R5)
    - Increase settling time (350ms→500ms) for better convergence
    - Increase tolerance (2000→3000 ticks) for noisy environments
    Trade-off: Test duration increases by ~2.25s total (7.5s→9.75s) but
    eliminates false failures in electrically noisy test environments.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
2026-01-16 test: Add comprehensive NVM wear leveling reliability tests
    Added 5 new hardware-in-the-loop tests to verify wear leveling implementation:
    - test_g_stress_extended_write_cycles: 100 consecutive writes to verify
    monotonic write count and no data corruption under stress
    - test_i_slot_fill_and_multiple_wraparounds: Verify correct slot rotation
    over 3× num_slots writes, testing wraparound behavior
    - test_j_write_count_never_decreases: Verify write count strictly increases
    and is unaffected by resets
    - test_k_remaining_writes_estimate_decreases: Verify remaining writes
    calculation accuracy (lifetime - write_count)
    - test_l_post_erase_state_clean: Verify all wear leveling state resets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
    [nvm.c]
2026-01-16 fix: Remove unnecessary RAMFUNC markers to fix GCC leb128 bug
    The NVM wear leveling functions (calculate_checksum, nvm_wl_validate_metadata,
    nvm_wl_scan_slots) do not need to run from RAM as they are not called from
    the 20 kHz control loop.
    Adding PAC5XXX_RAMFUNC to these functions triggered a GCC bug (versions 12.2+)
    where debug symbols (-g2) combined with RAM-placed functions generate undefined
    leb128 operands in the assembly output, causing build failures.
    The only functions that genuinely require RAM placement are the flash hardware
    access functions in flash_func.c (flash_erase_page, flash_write), which were
    already correctly marked in the original implementation.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
    [nvm.c]
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

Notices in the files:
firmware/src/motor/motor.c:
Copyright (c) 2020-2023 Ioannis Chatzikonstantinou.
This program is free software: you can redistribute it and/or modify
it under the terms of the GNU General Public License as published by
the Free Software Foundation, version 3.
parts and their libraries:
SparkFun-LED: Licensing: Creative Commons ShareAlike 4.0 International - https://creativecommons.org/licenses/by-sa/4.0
